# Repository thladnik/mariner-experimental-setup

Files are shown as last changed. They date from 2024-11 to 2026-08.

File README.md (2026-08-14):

## MARINER visual stimulation setup

This is the repository for MARINER - the **M**ultispectral **A**rena for **R**eal-time **I**nteractive **N**euronal and **E**thological **R**esearch. 

MARINER rendering

### Overview

[MARINER light path schematic](https://github.com/thladnik/mariner-experimental-setup/blob/main/MARINER_light_path_schematic_drawing.pdf)  (incl. dimensions for possible configuration)

[Bill of materials](https://github.com/thladnik/mariner-experimental-setup/blob/main/bill_of_materials.csv)

[Alignment guide](https://github.com/thladnik/mariner-experimental-setup/blob/main/alignment_guide/README.md)

[Explosion animations](https://github.com/thladnik/mariner-experimental-setup/blob/main/accessibility)

[Printable components](https://github.com/thladnik/mariner-experimental-setup/tree/main/printed_parts) (Mesh and design files)

### Components

#### Projector
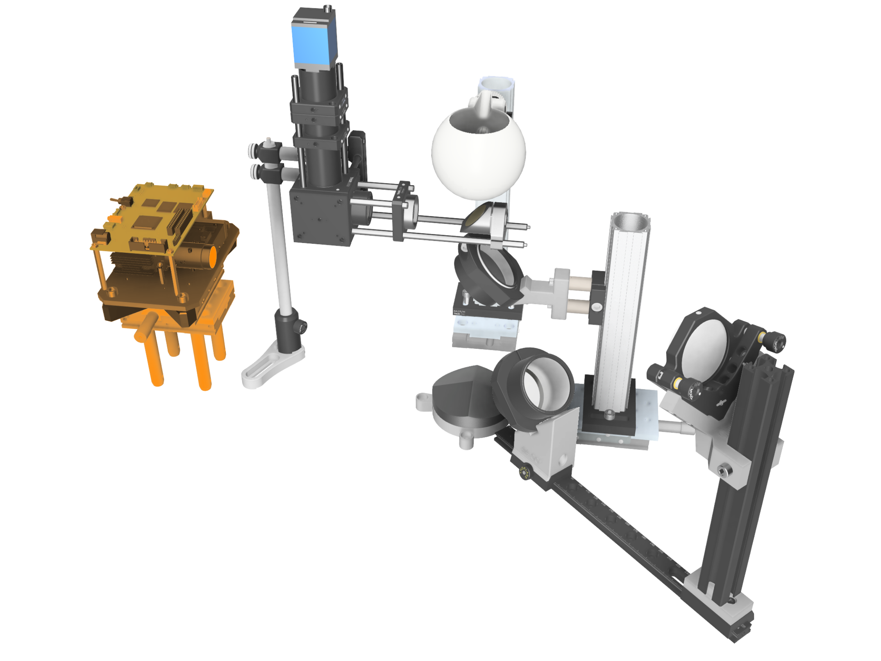
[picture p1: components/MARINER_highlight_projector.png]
MARINER projector


#### Center assembly
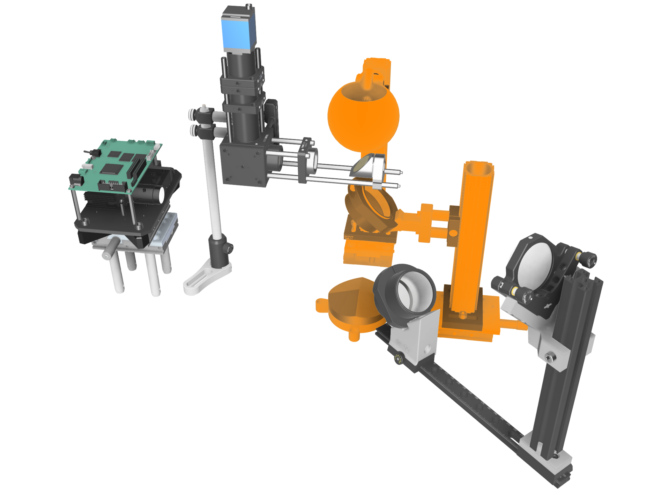
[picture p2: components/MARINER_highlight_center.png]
MARINER center assembly


#### Radial arms
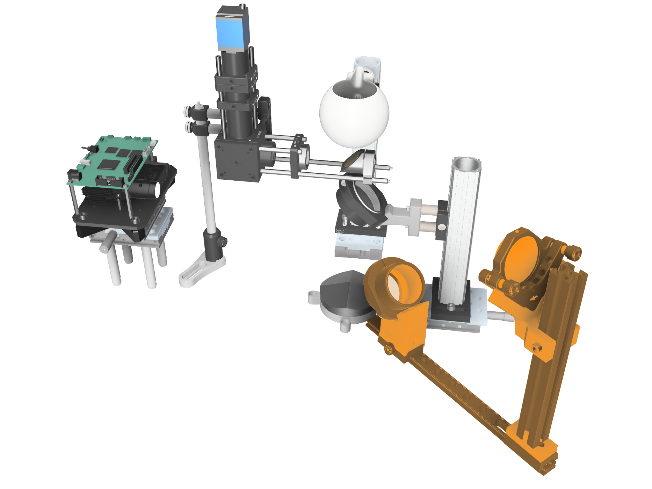
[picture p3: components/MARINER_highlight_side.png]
MARINER radial arms


#### (optional) Behavioral camera
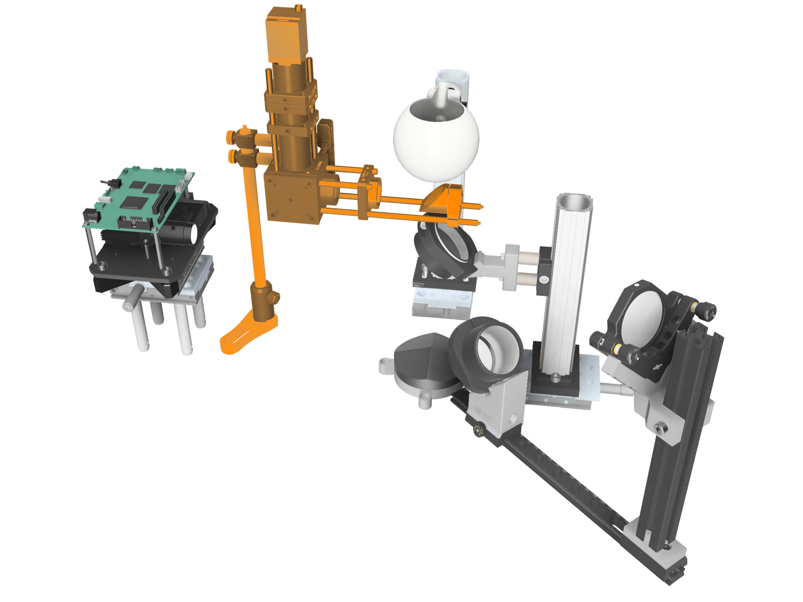
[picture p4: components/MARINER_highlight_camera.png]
MARINER camera


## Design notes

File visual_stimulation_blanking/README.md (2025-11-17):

# Circuit for blanking of the visual stimulation during 2p-imaging

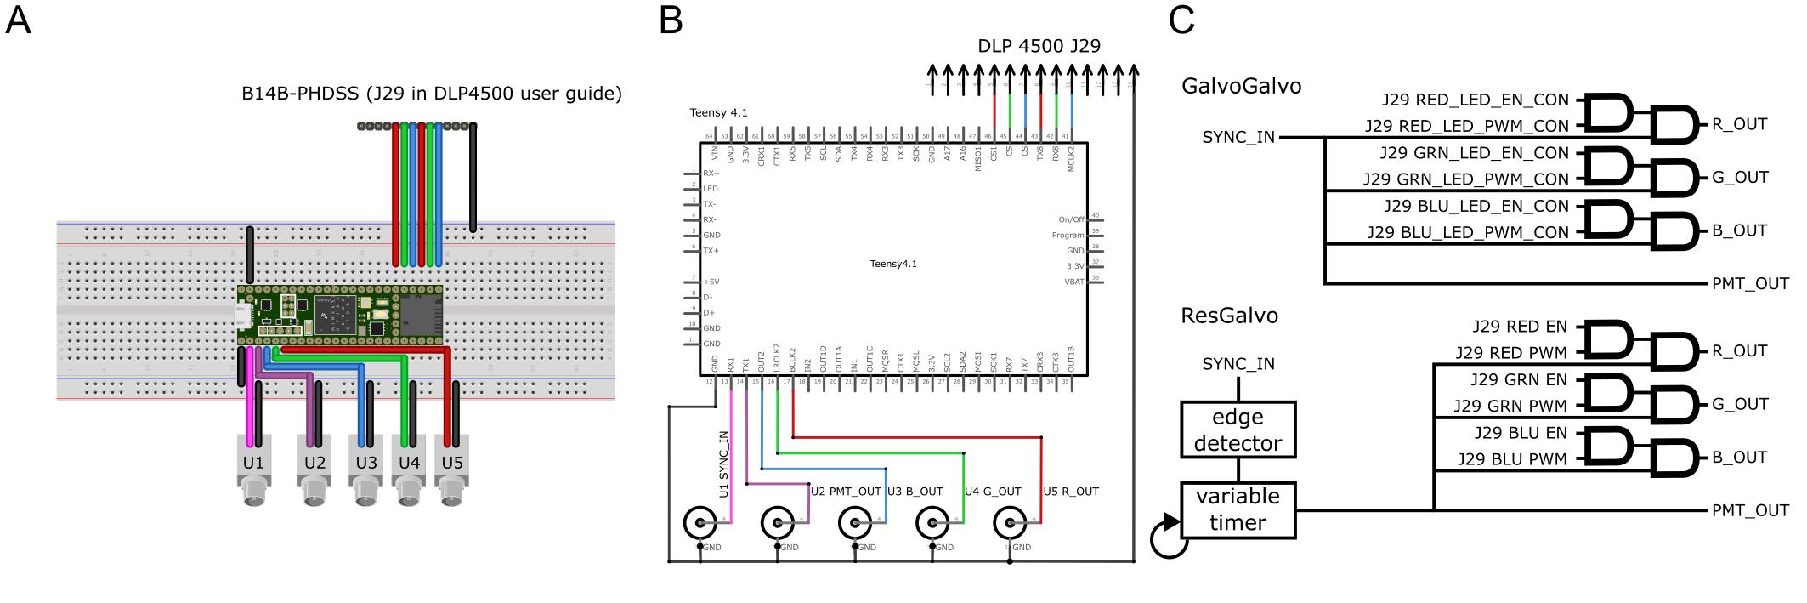
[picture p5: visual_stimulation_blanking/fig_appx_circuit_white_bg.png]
circuit-diagram-and-logic


### A and B
Image and schematic of the wiring between the Lightcrafter E4500MKII's J29 connector, the Teensy 4.1 microcontroller and the BNC input/output connectors for synchronized blanking to 2-photon imaging of the visual stimulation. 
U1 (sync_in): input for the scan synchronization signal. Either the linescan's flyback signal (for Galvo-Galvo) or the imaging frame synchronization signal (Resonant-Galvo)
U2 (pmt_out): optional digital output for gating of photomultiplier tubes (PMT).
U3-5 (<color>_out): digital output signal for controlling the LED light source (corresponding to the Lightcrafter's blue, green and red channels)

### C
Diagram of gating logic for GalvoGalvo and ResGalvo blanking. Note that both SYNC_IN and PMT_OUT may optionally be inverted, according to microscope or PMT specifications.

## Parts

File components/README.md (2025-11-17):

## Component list

Overview of the MARINER setup components references in the bill of materials ([BOM](https://github.com/thladnik/mariner-experimental-setup/blob/main/bill_of_materials.csv)).

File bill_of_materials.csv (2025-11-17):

Description | Manufacturer | Manufacturer ID | Quantity | Category | Note
Aluminum Breadboard, 600 mm x 600 mm x 12.7 mm, M6 Taps | Thorlabs | MB6060/M | 1 | Base
Industrial camera A2A1920-IMX392 | Basler | a2A1920-51gmBAS | 1 | Behavioral camera
USB 3.0 Camera Cable, Micro-B to Standard-A Plug, 8 m | Basler | Cable USB 3.0 Micro B sl/A, P, 8 m | 1 | Behavioral camera
N-BK7 Plano-Convex Lens, Ø1", f = 100 mm, AR Coating: 650–1050 nm | Thorlabs | LA1509-B | 1 | Behavioral camera
N-BK7 Plano-Convex Lens, Ø1", f = 200 mm, AR Coating: 650–1050 nm | Thorlabs | LA1708-B | 1 | Behavioral camera
30 mm Cage Cube | Thorlabs | C4W | 1 | Behavioral camera
Ø1" Optic Mount for 30 mm Cage Cube w/ Setscrew Retention | Thorlabs | B5C1 | 1 | Behavioral camera
30 mm Cage Cube Rotation Platform (Metric) | Thorlabs | B3CR/M | 1 | Behavioral camera
Blank Cover Plate, Metric | Thorlabs | B1C/M | 1 | Behavioral camera
30 mm Cage System Iris Diaphragm (Ø0.8–20 mm) | Thorlabs | CP20D | 1 | Behavioral camera
Right-Angle Kinematic Mount for Ø1" Optics, 30 mm Cage Compatible | Thorlabs | C45P | 1 | Behavioral camera
Ø1" Protected Gold Mirror | Thorlabs | PF10-03-M01 | 2 | Behavioral camera
Ø1" Adjustable Lens Tube, 0.81" Travel | Thorlabs | SM1V10 | 1 | Behavioral camera
SM1 Lens Tube, 0.50" Depth, SM1RR Retaining Ring, 5 Pack | Thorlabs | SM1L05-P5 | 1 | Behavioral camera
SM1 Lens Tube, 1.00" Depth, SM1RR Retaining Ring, 5 Pack | Thorlabs | M1L10-P5 | 1 | Behavioral camera
SM1-Threaded 30 mm Cage Plate, 0.35" Thick, 2 Retaining Rings, M4 Tap | Thorlabs | CP33/M | 3 | Behavioral camera
SM1-Threaded 30 mm Cage Plate, 0.50" Thick, 2 Retaining Rings, M4 Tap | Thorlabs | CP33T/M | 1 | Behavioral camera
30 mm Cage Plate w/ Removable Filter Holder, Ø1" Optics, M4 Tap | Thorlabs | CFH2R/M | 1 | Behavioral camera
Adapter, External C-Mount to External SM1, 3.2 mm Spacer | Thorlabs | SM1A39 | 1 | Behavioral camera
Externally SM1-Threaded End Cap | Thorlabs | SM1CP2 | 2 | Behavioral camera
Cage Assembly Rod, 8", Ø6 mm, 4 Pack | Thorlabs | ER8-P4 | 1 | Behavioral camera
Cage Assembly Rod, 4", Ø6 mm, 4 Pack | Thorlabs | ER4-P4 | 1 | Behavioral camera
Center mirror mount | 3D printed |  | 1 | Center assembly
Pyramid mirror mount | 3D printed |  | 1 | Center assembly
Bulb holder | 3D printed |  | 1 | Center assembly
Fishbowl | 3D printed |  | 1 | Center assembly
Pyramid mirror Ø80mm x 26.5mm, four-sided, 136° | LT Ultra-Precision Technology GmbH | 122680 | 1 | Center assembly | M2
50 mm Dovetail Translation Stage, M6 x 1.0 Taps | Thorlabs | DTS50/M | 2 | Center assembly | Most linear trans. stages w/ M6 taps should work
34 mm Construction Rail, L = 500 mm | Thorlabs | XT34-500 | 1 | Center assembly | Cut into 20 and 30cm piece
Magnetic Mounting Base, 50 mm x 75 mm x 10 mm | Thorlabs | BA2R/M | 2 | Center assembly
Dovetail Mounting Clamp for 34 mm Rails, Metric | Thorlabs | XT34HP/M | 2 | Center assembly
Ø12.7 mm Optical Post, SS, M4 Setscrew, M6 Tap, L = 30 mm | Thorlabs | TR30/M | 2 | Center assembly
SM2 Lens Tube Without External Threads, 1" Thread Depth | Thorlabs | SM2M10 | 1 | Center assembly
Ø2" Broadband Dielectric Mirror, 400 - 750 nm | Thorlabs | BB2-E02 | 1 | Center assembly | M1
Slip Ring for SM2 Lens Tubes, M4 Tap | Thorlabs | SM2RC/M | 1 | Center assembly
Teensy breakout box | 3D printed |  | 1 | Lighting
Socket connector, 36-pin, separable | BKL electronic | 10120802 | 4 | Lighting | Or similar socket connector
Lightcrafter LED signal connector | JST | PHDR-14VS | 1 | Lighting
Lightcrafter LED signal connector cables | JST | APAPA22K254 | 14 | Lighting
BNC cable | NEDIS | CVGL01000BK50 | 5 | Lighting | Or similar BNC cable
Microcontroller Teensy 4.1 with header | PJRC | TEENSY41H | 1 | Lighting
Dot-strip matrix PCB Laminated paper, 50x100 mm | Rademacher | H25PS050 | 1 | Lighting | Or similar dot-strip matrix PCB
BNC panel socket, central mounting, soldered vers. | Radiall | R141A 605 000 | 5 | Lighting | Or similar BNC panel socket
Chrolis 6-LED light source | Thorlabs | CHROLIS | 1 | Lighting | 625-590-565-475-420-365nm
Chrolis Breakout Box | Thorlabs | BBC1 | 1 | Lighting
Lightcrafter mounting platform | 3D printed |  | 1 | Projector
Lightcrafter lens holder | 3D printed |  | 1 | Projector
0.45" DLP® Fiber couple E4500MKII™ Development Module LLG On Axis Projection | EKB technologies | DPM-FE4500MKIIFLLGOX | 1 | Projector
7" x 4" Lab Jack, 2.26" Vertical Travel, 75 lbs Load Capacity, M6 Taps | Thorlabs | L490/M | 1 | Projector | This is mostly for convenience, 50 or 75mm 1/2" posts should also work instead (4x TR50/M or 4x TR75/M)
Ø1" Achromatic Doublet, ARC: 400 - 700 nm, f = 60 mm | Thorlabs | AC254-060-A | 1 | Projector | L1
50 mm Dovetail Translation Stage, M6 x 1.0 Taps | Thorlabs | DTS50/M | 2 | Projector | Most linear trans. stages with M6 taps should work
Set of jumper wires |  |  | ~20 | Projector | Any jumper wires compatible with choosen socket connector
Angled slip ring holder for lenses | 3D printed |  | 4 | Radial arms
Angled holder for Kinematic mirror mount | 3D printed |  | 4 | Radial arms
Construction rail mount to dovetail rail carrier | 3D printed |  | 4 | Radial arms
Slip Ring for SM2 Lens Tubes, M4 Tap | Thorlabs | SM2RC/M | 4 | Radial arms
Kinematic Mirror Mount for Ø2" Optics with Visible Laser Quality Mirror | Thorlabs | KM200-E02 | 4 | Radial arms | M3
Dovetail Optical Rail, 300 mm, Metric | Thorlabs | RLA300/M | 4 | Radial arms
Dovetail Rail Carrier, 50.8 mm x 25.4 mm, M6 Counterbore, M4 Taps | Thorlabs | RC2/M | 8 | Radial arms
Ø2" Achromatic Doublet, ARC: 400 - 700 nm, f = 75.0 mm | Thorlabs | AC508-075-A | 4 | Radial arms | L2
SM2 Lens Tube, 2" Thread Depth, One Retaining Ring Included | Thorlabs | SM2L20 | 4 | Radial arms
25 mm Square Construction Rail, 225 mm Long, M6 Taps | Thorlabs | XE25L225/M | 4 | Radial arms
Low-Profile T-Nut, M6 x 1.0 Tapped Hole, 10 Pack | Thorlabs | XE25T3/M | 2 | Radial arms

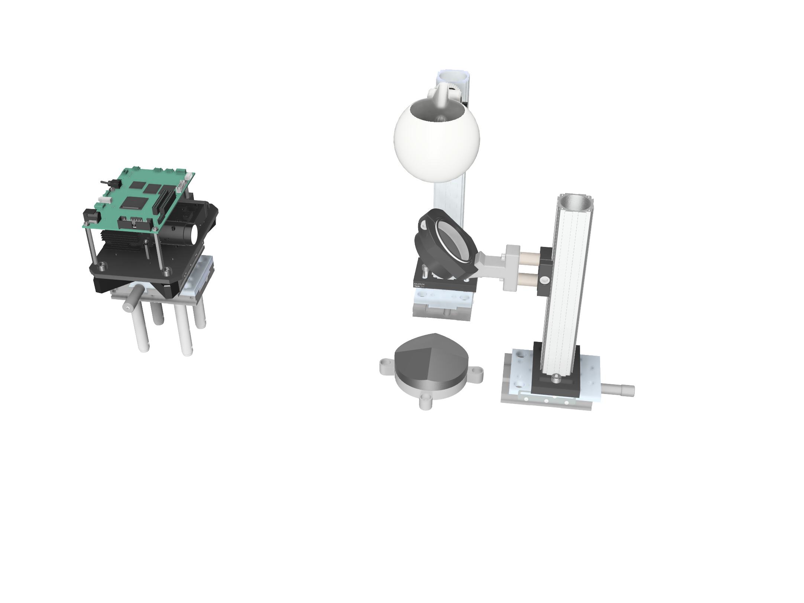
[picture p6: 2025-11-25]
components/MARINER_projector_center.png

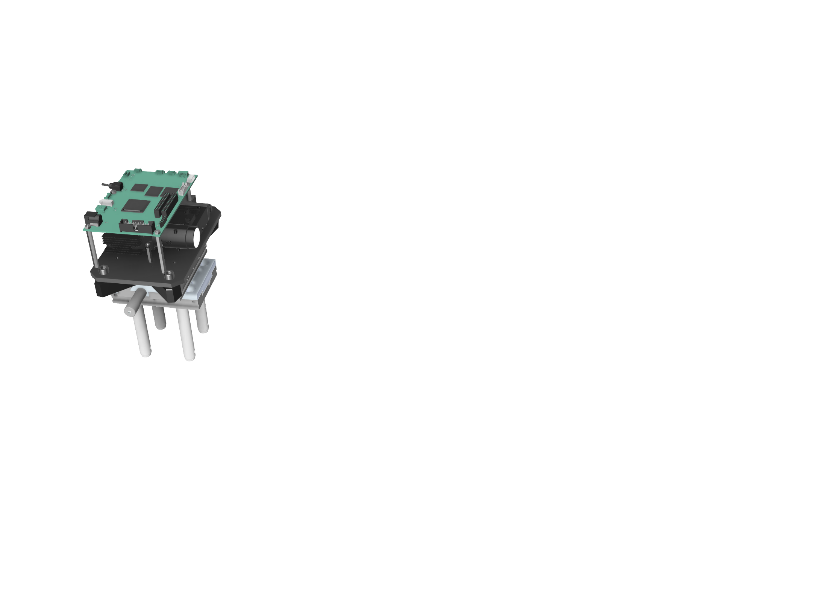
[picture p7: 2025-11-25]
components/MARINER_projector.png

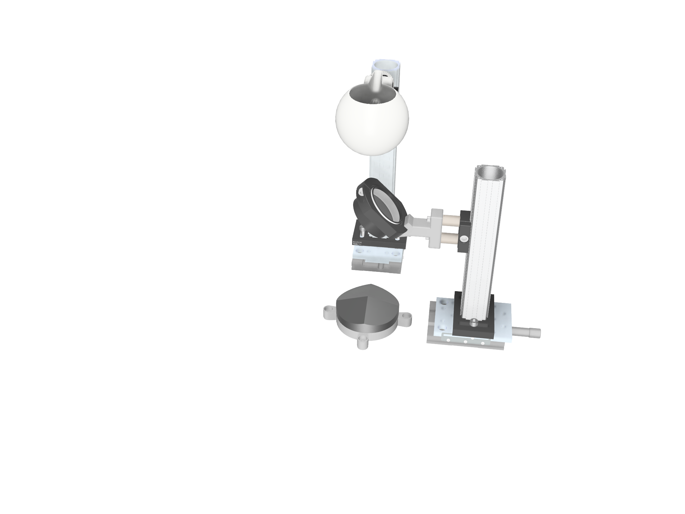
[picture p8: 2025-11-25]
components/MARINER_center.png

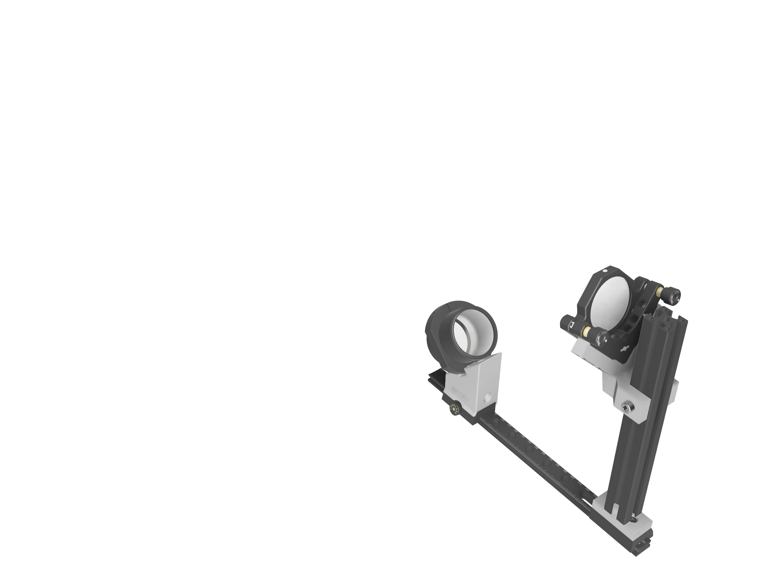
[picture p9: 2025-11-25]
components/MARINER_side.png

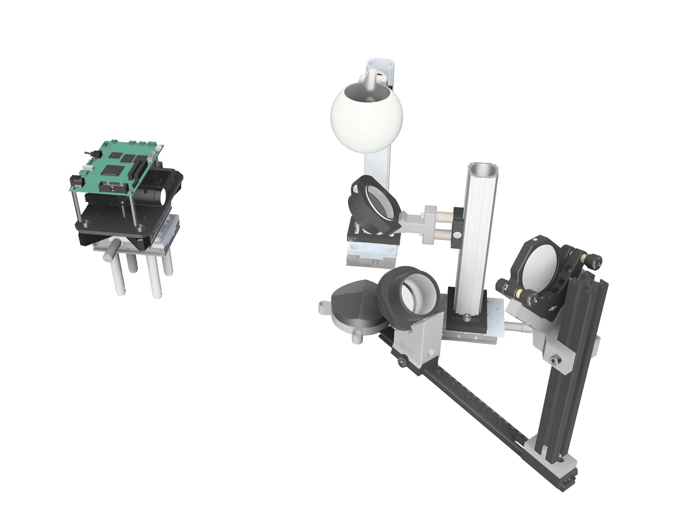
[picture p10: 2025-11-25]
components/MARINER_projector_center_side.png

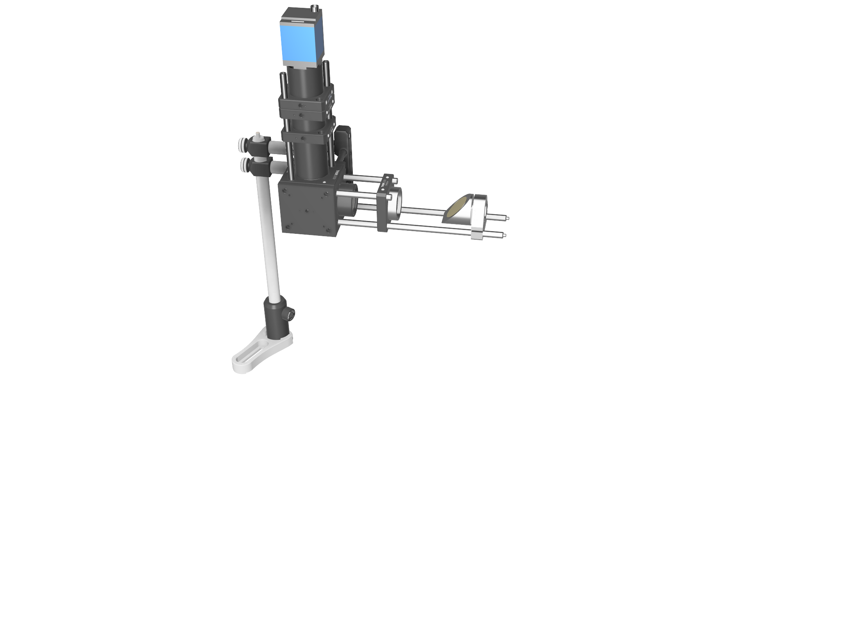
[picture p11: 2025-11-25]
components/MARINER_camera.png

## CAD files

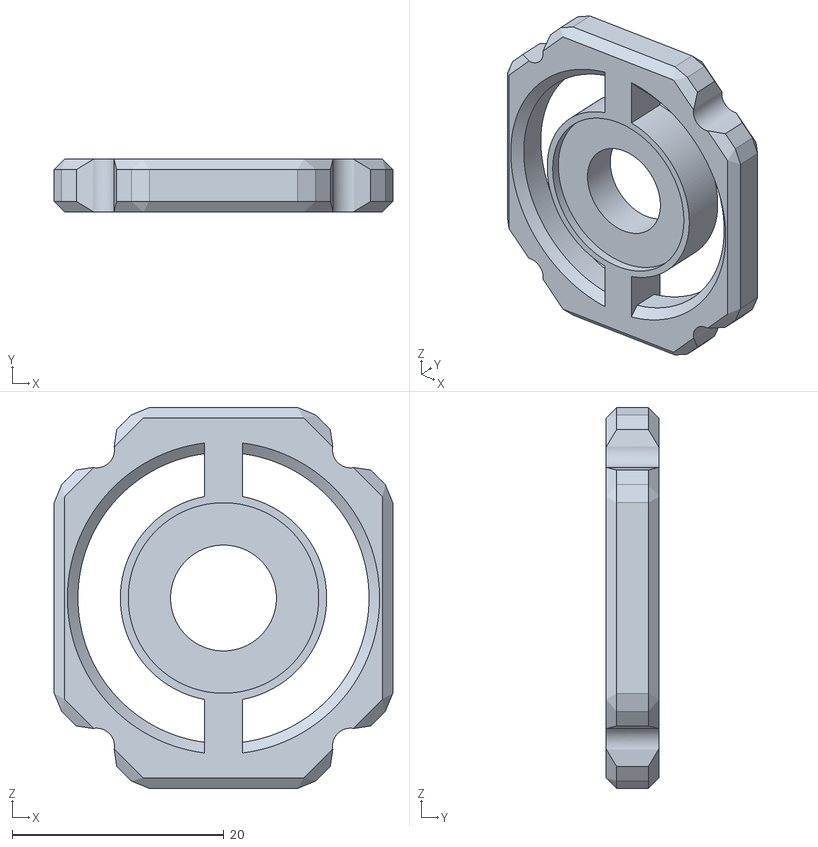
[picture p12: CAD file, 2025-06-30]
printed_parts/Fishbowl_with_rail_mount_Spacer.stl
32.0 x 5.00 x 36.0

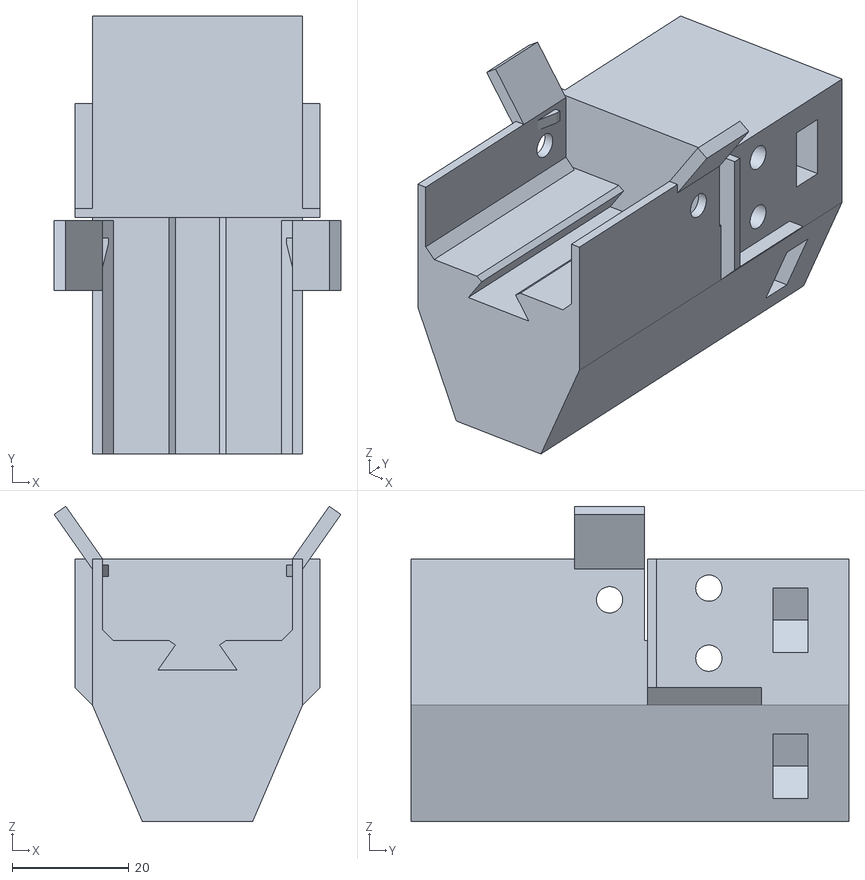
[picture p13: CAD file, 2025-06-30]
printed_parts/Fishbowl_with_rail_mount_Rail_mount.stl
49.1 x 75.0 x 54.0

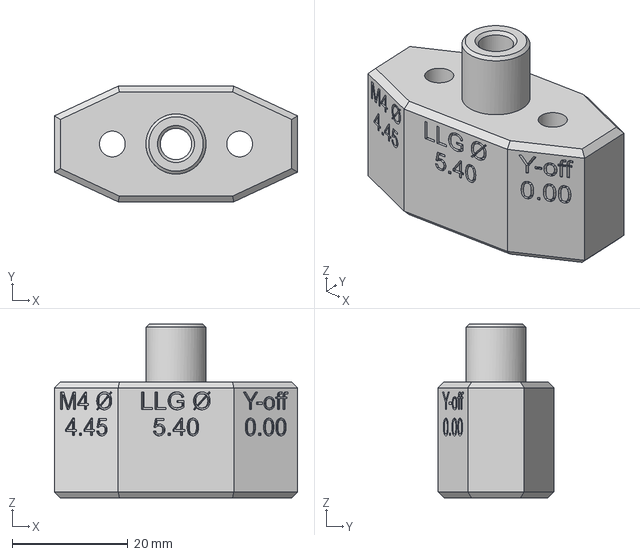
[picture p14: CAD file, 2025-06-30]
printed_parts/Lightcrafter_LLG_3mm_adapter.iges
42.0 x 20.0 x 30.0 mm

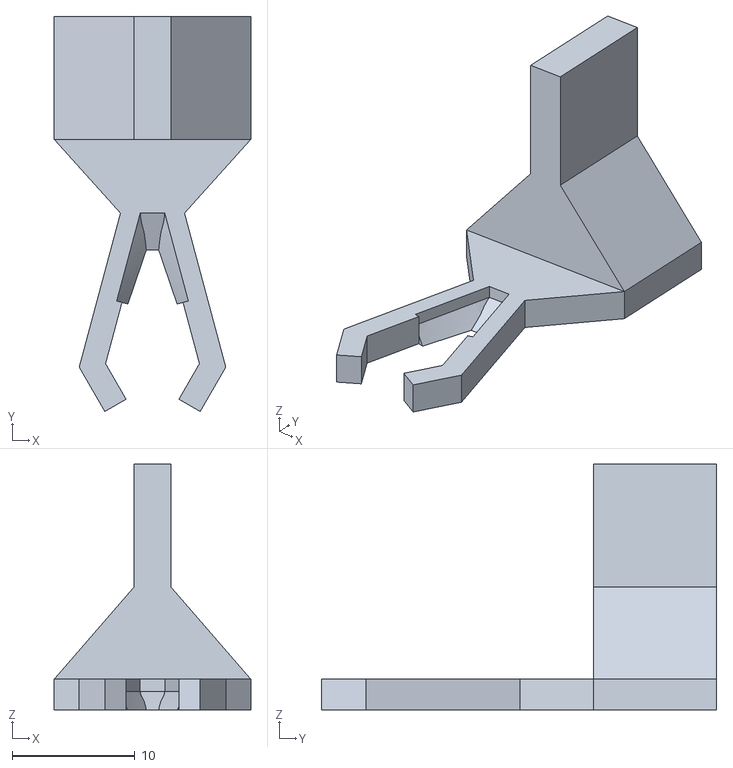
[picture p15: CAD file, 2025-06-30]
printed_parts/Fish_mounting_rod_Mold.stl
16.0 x 32.1 x 20.0

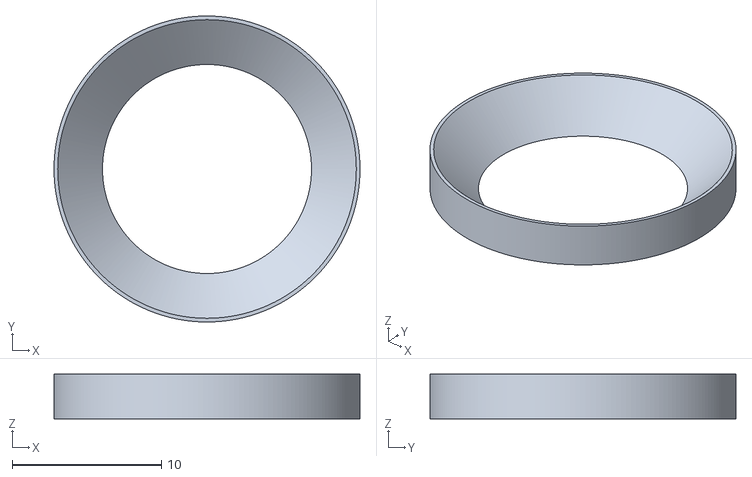
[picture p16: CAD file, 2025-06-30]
printed_parts/Lightcrafter_lens_mount_aperture.stl
20.5 x 20.5 x 3.00

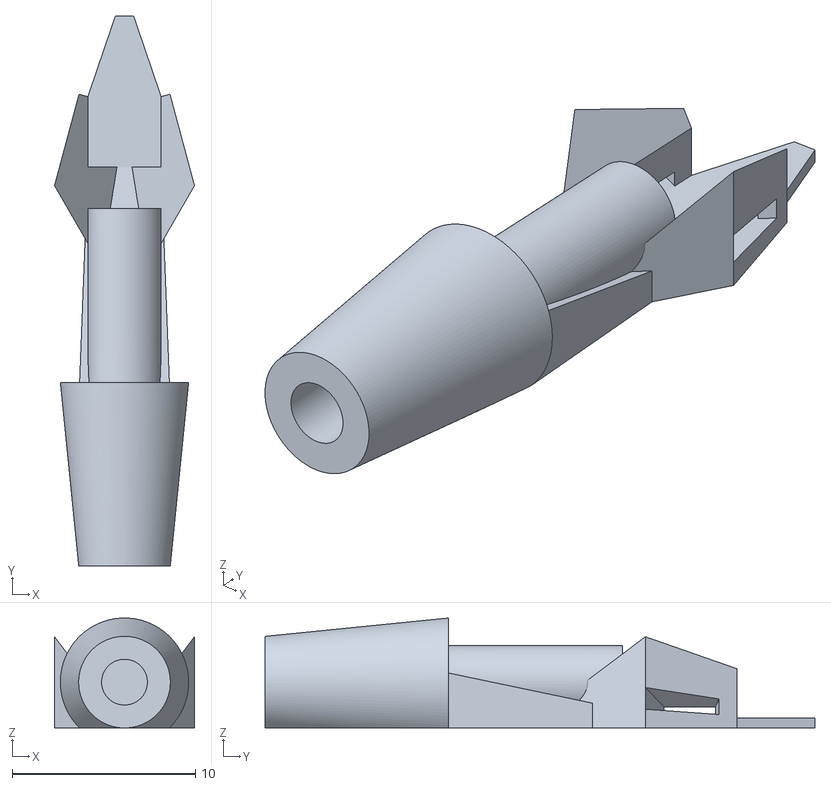
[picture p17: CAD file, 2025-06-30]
printed_parts/Fish_mounting_rod_Arrowhead.stl
7.64 x 30.0 x 6.00

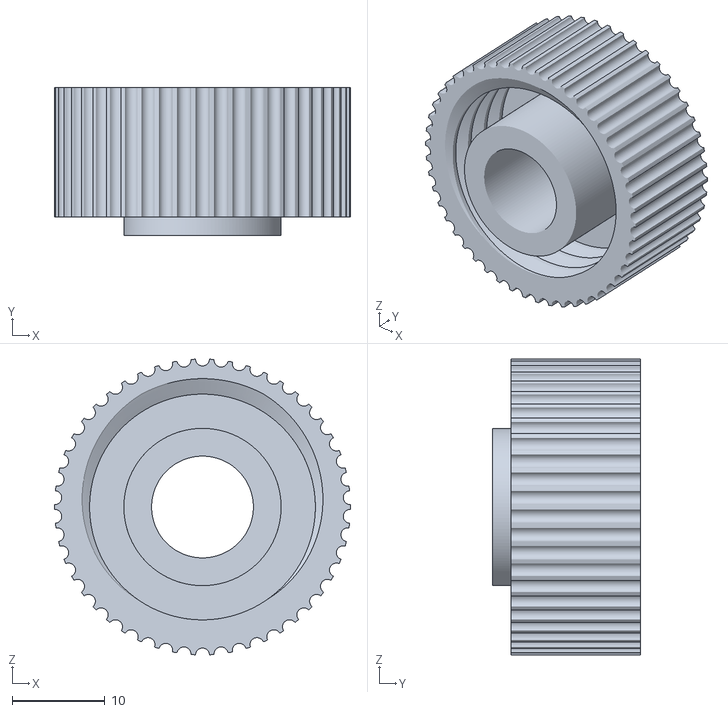
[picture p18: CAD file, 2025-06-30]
printed_parts/Fishbowl_with_rail_mount_Cap.stl
32.0 x 16.0 x 32.0

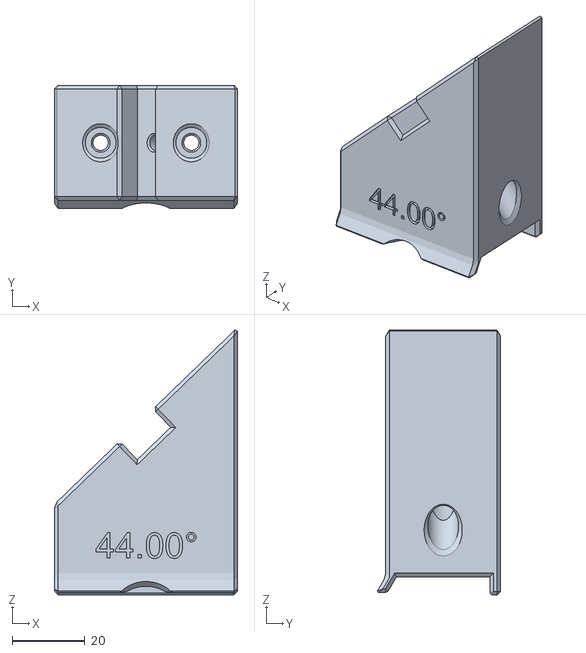
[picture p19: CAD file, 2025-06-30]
printed_parts/Lens_mount_side_44deg.stl
50.5 x 34.0 x 73.1

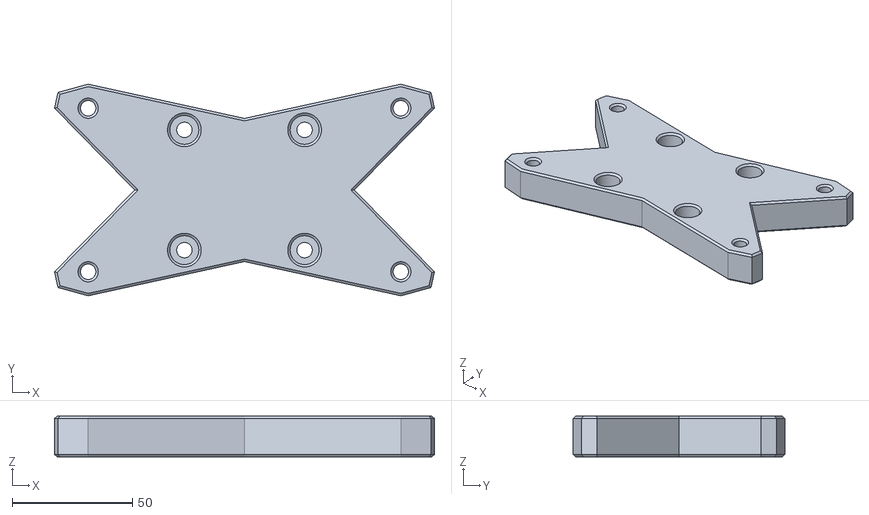
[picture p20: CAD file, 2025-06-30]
printed_parts/Lightcrafter_mounting_platform.stl
158.0 x 88.0 x 17.0

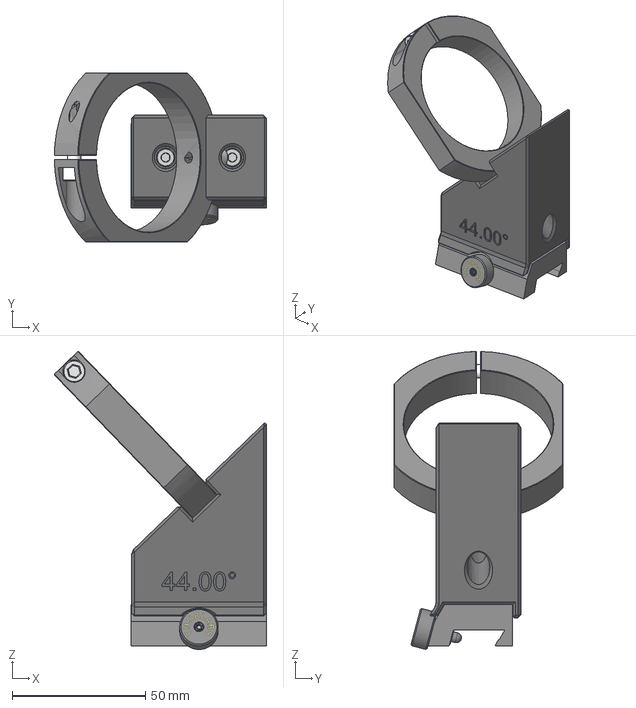
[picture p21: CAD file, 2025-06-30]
printed_parts/Lens_mount_side.iges
79.6 x 63.5 x 111.8 mm

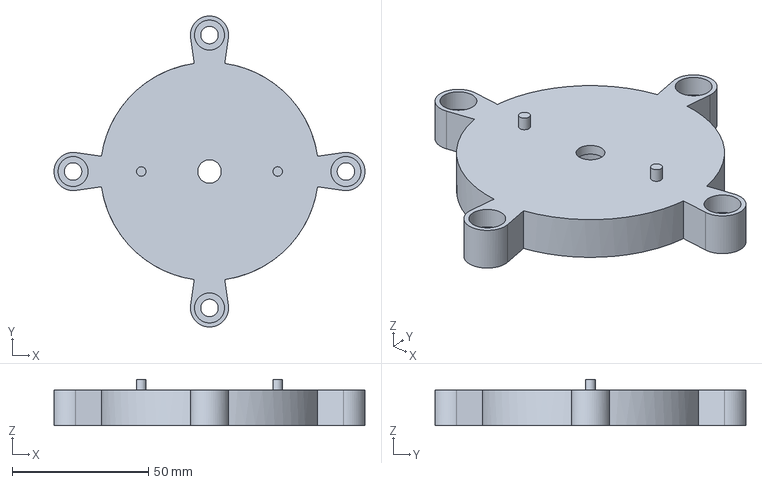
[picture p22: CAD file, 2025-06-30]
printed_parts/Pyramid_mirror_mount.iges
114.0 x 114.0 x 17.0 mm

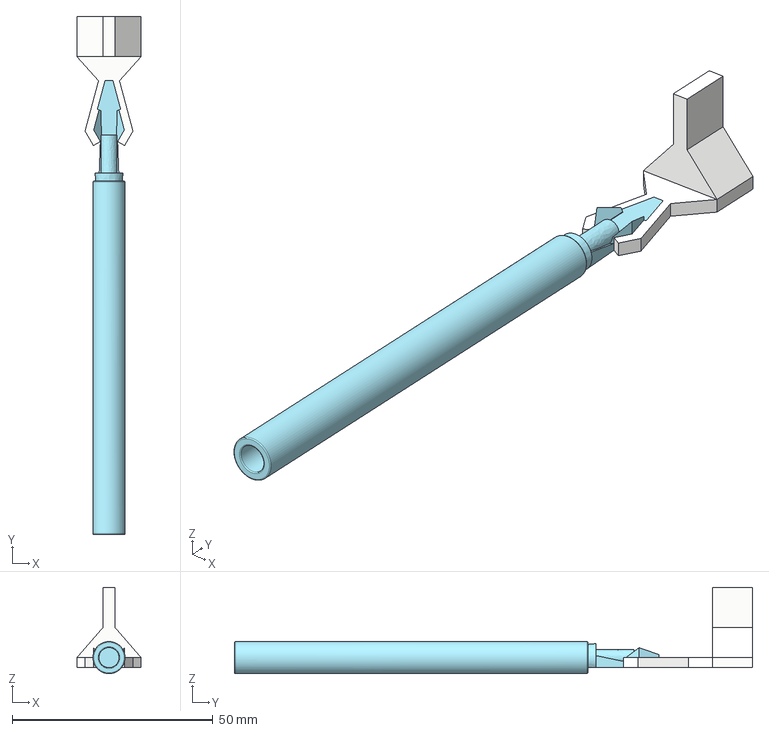
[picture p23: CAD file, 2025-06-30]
printed_parts/Fish_mounting_rod.iges
16.0 x 129.0 x 21.5 mm

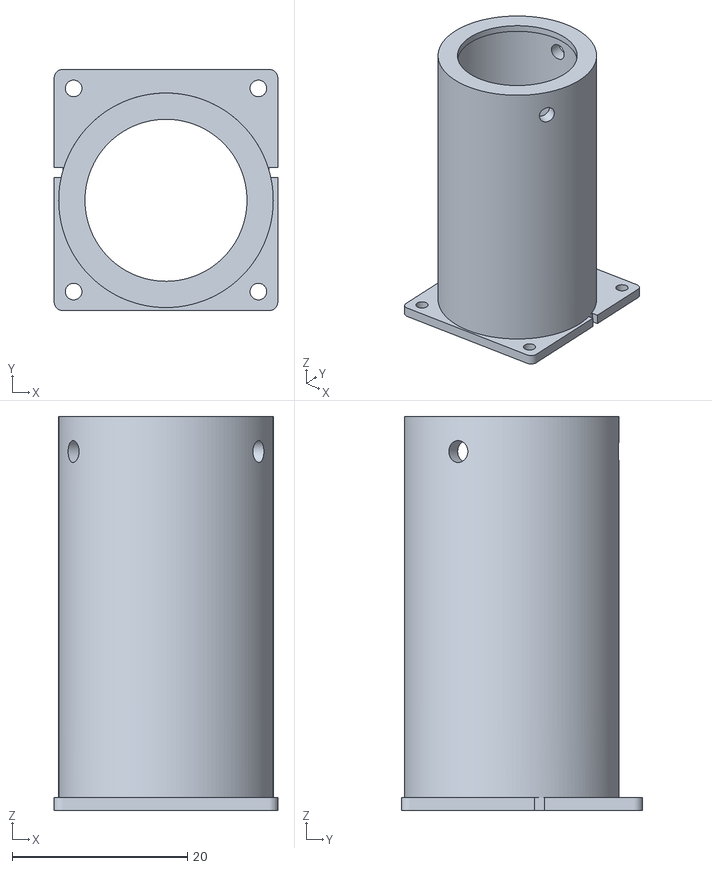
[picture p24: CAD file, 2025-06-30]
printed_parts/Lightcrafter_lens_mount_housing.stl
25.5 x 27.6 x 45.0

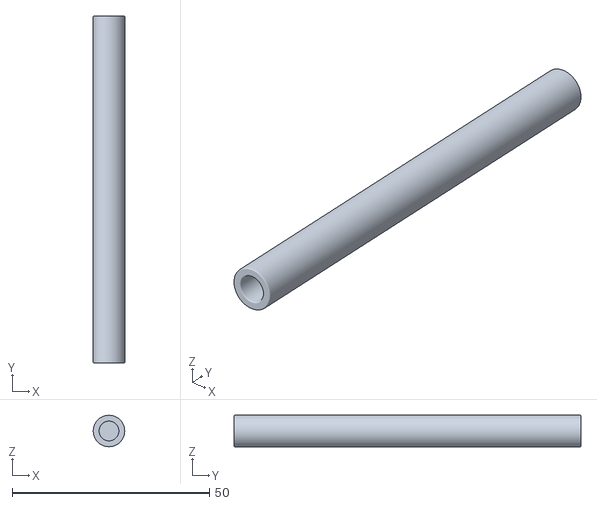
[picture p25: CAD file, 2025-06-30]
printed_parts/Fish_mounting_rod_Rod.stl
8.00 x 88.0 x 8.00

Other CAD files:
printed_parts/Fishbowl_with_rail_mount_Bulb.stl
printed_parts/Fishbowl_with_rail_mount.iges
printed_parts/Mirror_center_45deg.iges
printed_parts/Fish_mounting_rod.f3d
printed_parts/Fishbowl_with_rail_mount.f3d
printed_parts/Lens_mount_side.f3z
printed_parts/Lightcrafter_LLG_3mm_adapter.f3d
printed_parts/Lightcrafter_LLG_3mm_adapter.stl
printed_parts/Lightcrafter_lens_mount.f3d
printed_parts/Lightcrafter_mounting_platform.f3z
printed_parts/Mirror_center_45deg.f3d
printed_parts/Mirror_center_45deg.stl
printed_parts/Pyramid_mirror_mount.f3d
printed_parts/Pyramid_mirror_mount.stl

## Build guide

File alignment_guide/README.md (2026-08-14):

# Spherical Projection Setup — Light Path & Alignment Tutorial

This tutorial explains how the projection light path of the spherical MARINER stimulation setup works and walks you through aligning it from scratch. It is written for both new and experienced users: Section 1–2 give you the background you need to understand *why* each adjustment exists; Sections 3–5 are the hands-on procedure you can follow step by step at the rig.

---

## 1. System overview

The setup projects visual stimuli onto a **glass sphere** using a **single video projector** whose image is split into **four separate projections**, one per side of the sphere.

The visual transform required for the four-sided clover projection is available in the accompanying stimulation software [vxPy](https://github.com/thladnik/vxpy). 
The MARINER setup calibration may be started using vxPy's calibration function (`vxpy -c path/to/config.yaml calibrate`). For further information please refer to the software documentation.

The main hardware components are:

| Component | Role |
|---|---|
| **LightCrafter video projector** (on a sideways translation stage + dovetail rail) | Image source (DMD-based projector) |
| **Custom projection lens** — 1/2″ 40 mm lens (1″ 40 mm for the FC variant) | Replaces/extends the stock projector optics |
| **45° mirror** | Folds the horizontal projector beam downward |
| **4-sided pyramidal mirror** | Splits the image into four quadrants, one per projection arm |
| **4× lenses at 46° to horizontal** — 2″ f = 75 mm achromats | Refocus each image quadrant on its way out to the side |
| **4× kinematic mirrors at 12 to 14°** | Redirect each refocused quadrant up and onto the glass sphere |
| **Fishbowl** | The projection target |

**Why a 4-sided pyramidal mirror?** Covering the sphere from four sides gives steeper angles of incidence on the sphere surface, more even illumination, and less out-of-focus light than fewer, shallower projections would.

---

## 2. The light path, step by step

Light path schematic: LightCrafter → 45° mirror → pyramidal mirror → 46° lens → 12° kinematic mirror → glass sphere

*Figure 1 — The full light path (one of the four arms shown, side view). The numbered badges match the steps below.*

Follow one image quadrant from projector to sphere:

1. The **LightCrafter** projects the full stimulus image horizontally through its **custom lens**.
2. The **45° mirror** folds the beam straight down.
3. The beam lands centered on the apex of the **4-sided pyramidal mirror**, which splits the image into its four quadrants and reflects each quadrant outward toward one of the four sides.
4. Each quadrant passes through a **46° lens** (2″ f = 75 mm achromat), which refocuses that part of the image.
5. A **12° kinematic mirror** on each side reflects the refocused quadrant back toward the center and up onto the **glass sphere**.

When everything is aligned, the four quadrants form a four-lobed pattern that is perfectly centered on the pyramidal mirror, and the four projections meet seamlessly on the sphere.

---

## 3. Before you start

- All software adjustments described below are made in the **startup configuration window** of the display software, mainly on the **DISPLAY tab**. You will use:
  - **Display calibration → Planar Checkerboard** (with its vertical/horizontal spatial-frequency settings) as the main test pattern for centering the image.
  - The **spherical mesh** pattern (or the checkerboard) for aligning the side arms.
  - The **X-position / Y-position** offset settings (Global section) and the **radial offset** and **scale** settings (Spherical section).
- The alignment order matters. Work through the sections in sequence:
  1. Center the image on the pyramidal mirror (Section 4).
  2. Fine-tune X/Y centering with the checkerboard procedure (Section 4.3).
  3. Align each of the four side arms (Section 5).

---

## 4. Center part: getting the image onto the pyramidal mirror

The goal of this stage is to have the projected image land **centered on the apex of the pyramidal mirror**, with the light path passing through the **center of the projection lens**. If the beam is off-axis through the lens or off-center on the pyramid, the four quadrants will be unevenly sized and distorted downstream (see Section 4.3 for how to detect and fix this).

Center alignment: X via translation stage (top view), Y via 45° mirror rail and slip ring (side view), goal pattern

*Figure 2 — The two centering adjustments and the target result: four symmetric lobes centered on the pyramid apex.*

### 4.1 X translation (left–right)

The X position of the image on the pyramidal mirror is adjusted **physically**, by moving the **LightCrafter sideways on its translation stage**. Sliding the projector left/right shifts the image left/right on the pyramid.

### 4.2 Y translation (front–back)

There is no single knob for Y. Instead, combine two movements of the **45° mirror**:

- **Up–down** movement of the mirror mount along the vertical optical rail, and
- **Forward–backward** movement of the mirror within its slip ring.

Together these shift the image along the Y axis on the pyramidal mirror. Iterate both until the four-lobed test pattern sits centered on the pyramid apex (compare with the "end result" reference: four symmetric lobes, one per mirror facet).

### 4.3 Fine centering with the Planar Checkerboard (parallax method)

Even when the image *looks* centered, it may still pass **off-axis** through the projection lens — note that with the custom lens, the image on the DMD chip itself may be off-axis. The following software-assisted procedure detects this: if the projection axis is off-center, the image will drift sideways when you change the virtual target distance.

Display the **Planar Checkerboard** pattern, then move the **target slider from front to back** and watch how the image moves.

Parallax check: off-axis light paths make the image drift when the target distance changes; a centered path does not

*Figure 3 — The parallax check. Only a light path through the lens center keeps the image stationary while the target slider is swept.*

**X alignment:**

- Image drifts **left** as the target moves back:
  1. **Decrease** the **X-position** offset setting.
  2. Move the target slider back to the front.
  3. Move the **translation stage left** to re-center the image.
- Image drifts **right**:
  1. **Increase** the **X-position** offset setting.
  2. Move the target to the front.
  3. Move the **translation stage right** to re-center.

**Y alignment (same logic, vertical axis):**

- Image drifts **up** as the target moves back:
  1. **Increase** the **Y-position** offset setting.
  2. Move the target to the front.
  3. Re-center the image **upward** (using the 45° mirror rail/slip-ring adjustments from Section 4.2).
- Image drifts **down**:
  1. **Decrease** the **Y-position** offset setting.
  2. Move the target to the front.
  3. Re-center the image **downward**.

Repeat each loop until sweeping the target slider from front to back no longer shifts the image. At that point the light path is centered through the lens and on the pyramid.

---

## 5. Side arms (repeat 4×)

Each of the four projection arms is aligned independently, but with the same procedure. Each arm consists of a **46° lens** (2″ f = 75 mm achromat) and a **12° kinematic mirror**; the lens refocuses the quadrant, and the mirror sends it up onto the sphere.

Side arm degrees of freedom: lens height and focus, mirror height and distance, kinematic elevation and azimuth

*Figure 4 — All adjustment axes of one side arm, and the order in which to work through them (Sections 5.1–5.4).*

### 5.1 Find the optical center of the arm's lens

1. In the software, set a **fixed radial offset**.
2. Set the **scale multiplier small (< 0.2)** — this shrinks the quadrant to a small patch so you can see where it passes through the lens.
3. Display the **spherical mesh** or **checkerboard** pattern.
4. Adjust until the light path passes through the **center of the lens**.

> **Tip:** Low-f lenses produce pincushion distortion toward their edges — another reason the beam must go through the lens center rather than near its rim.

### 5.2 Lens alignment

The lens has two degrees of freedom:

- **Lens height** — translate the lens mount along its rail.
- **Lens focus** — translate the lens within its slip ring, along the optical axis.

### 5.3 Mirror holder alignment

The kinematic mirror's holder can be adjusted in **height** and in **distance** (along its rail). Use these to:

- move the image **into focus** on the sphere,
- **scale** the image, and
- change the **vertical image offset** on the sphere.

### 5.4 Kinematic mount fine-tuning

Finally, use the kinematic mount's adjustment screws to set the projection's:

- **Elevation** on the sphere, and
- **Azimuth** on the sphere.

This places the quadrant precisely on its quarter of the sphere. Repeat Sections 5.1–5.4 for the remaining three arms.

> **Note:** the kinematic mirror is mounted at a 45° around the optical axis, so that the adjustment screws are positioned symmetrically. This means for pure azimuth or elevation adjustments both screws need to be adjusted simultaneously.

---

## 6. Verifying the alignment

You are done when:

- The four-lobed test pattern is symmetric and centered on the pyramidal mirror (Section 4).
- Sweeping the checkerboard target slider front↔back produces no image drift in X or Y (Section 4.3).
- Each quadrant passes through the center of its side lens, is in focus on the sphere, and the four projections meet at the correct elevation and azimuth so the sphere is covered evenly from all four sides (Section 5).

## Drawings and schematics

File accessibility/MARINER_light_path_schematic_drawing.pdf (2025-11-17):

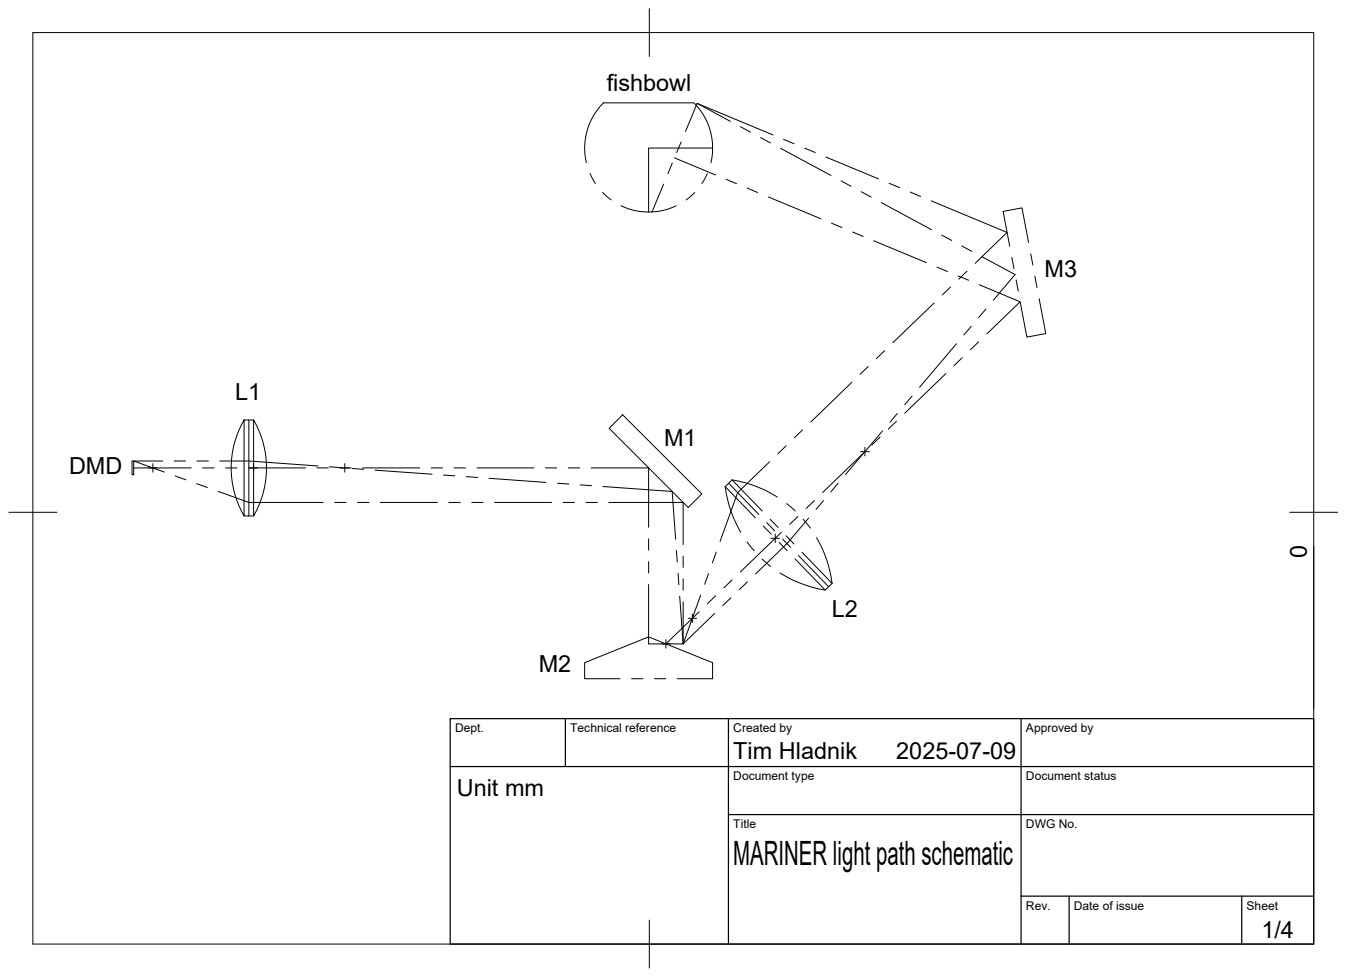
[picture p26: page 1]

Dept. | Technical reference | Created by Tim Hladnik 2025-07-09 | Approved by

Unit mm | | Document type | Document status

Title MARINER light path schematic | DWG No.

Rev. | Date of issue | Sheet

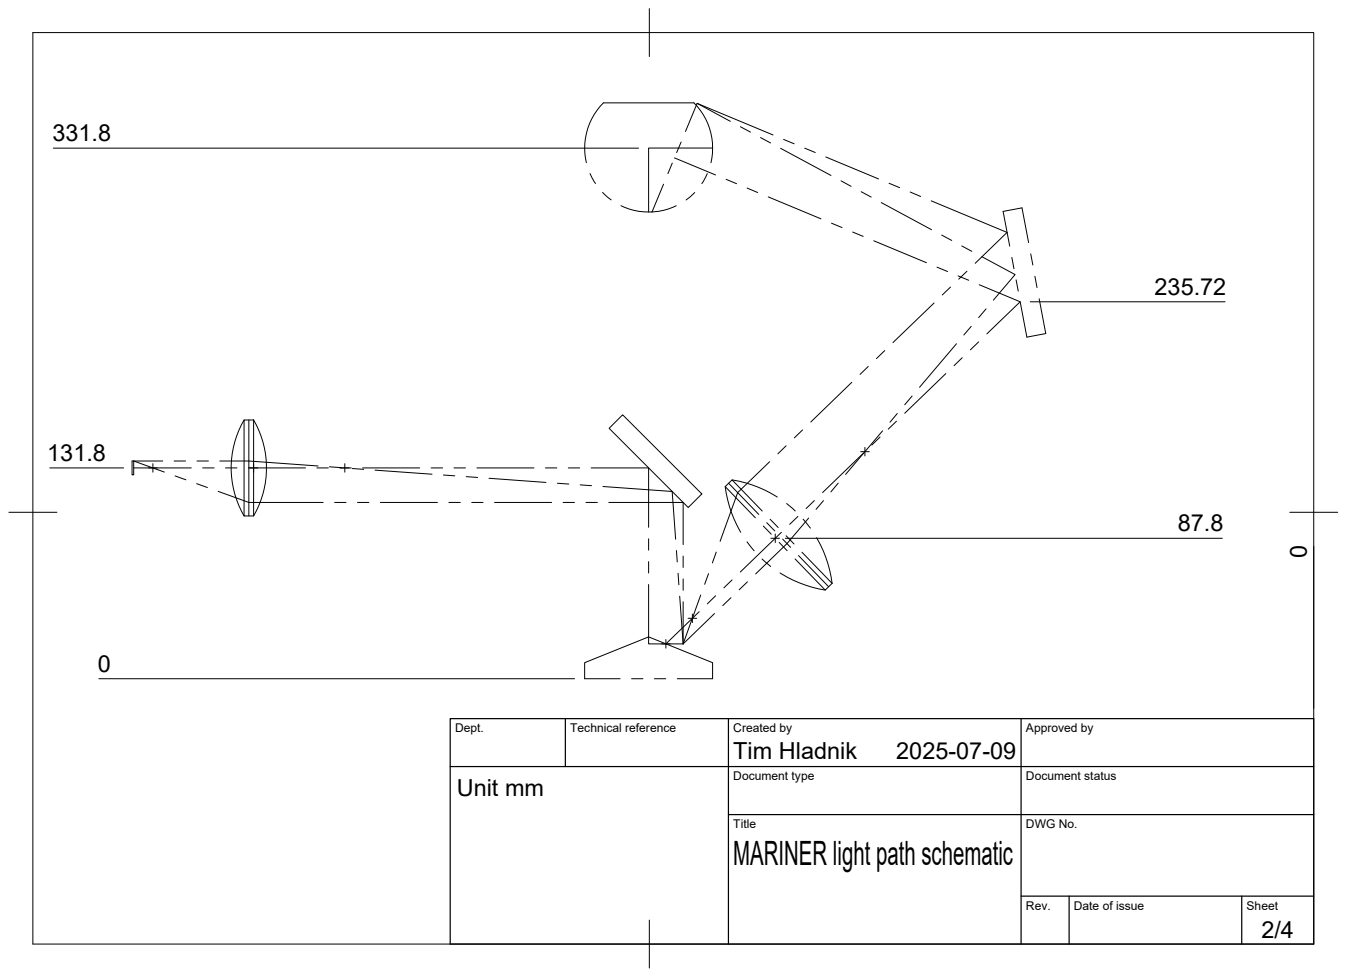
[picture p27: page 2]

Dept. | Technical reference | Created by Tim Hladnik 2025-07-09 | Approved by

Unit mm | | Document type | Document status

Title MARINER light path schematic | DWG No.

Rev. | Date of issue | Sheet

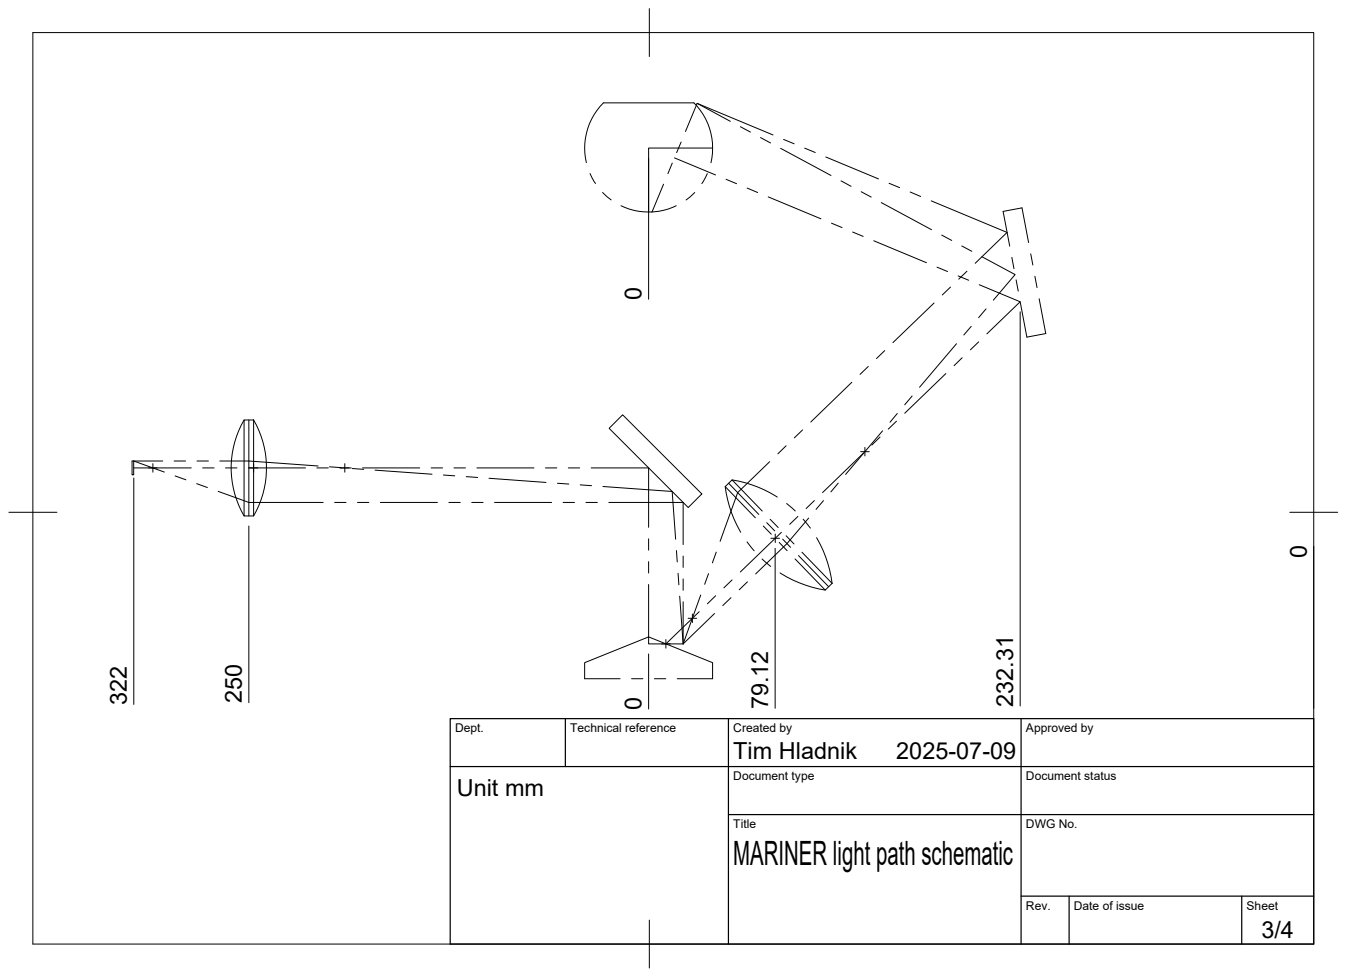
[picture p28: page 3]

Dept. | Technical reference | Created by Tim Hladnik 2025-07-09 | Approved by

Unit mm | | Document type | Document status

Title MARINER light path schematic | DWG No.

Rev. | Date of issue | Sheet

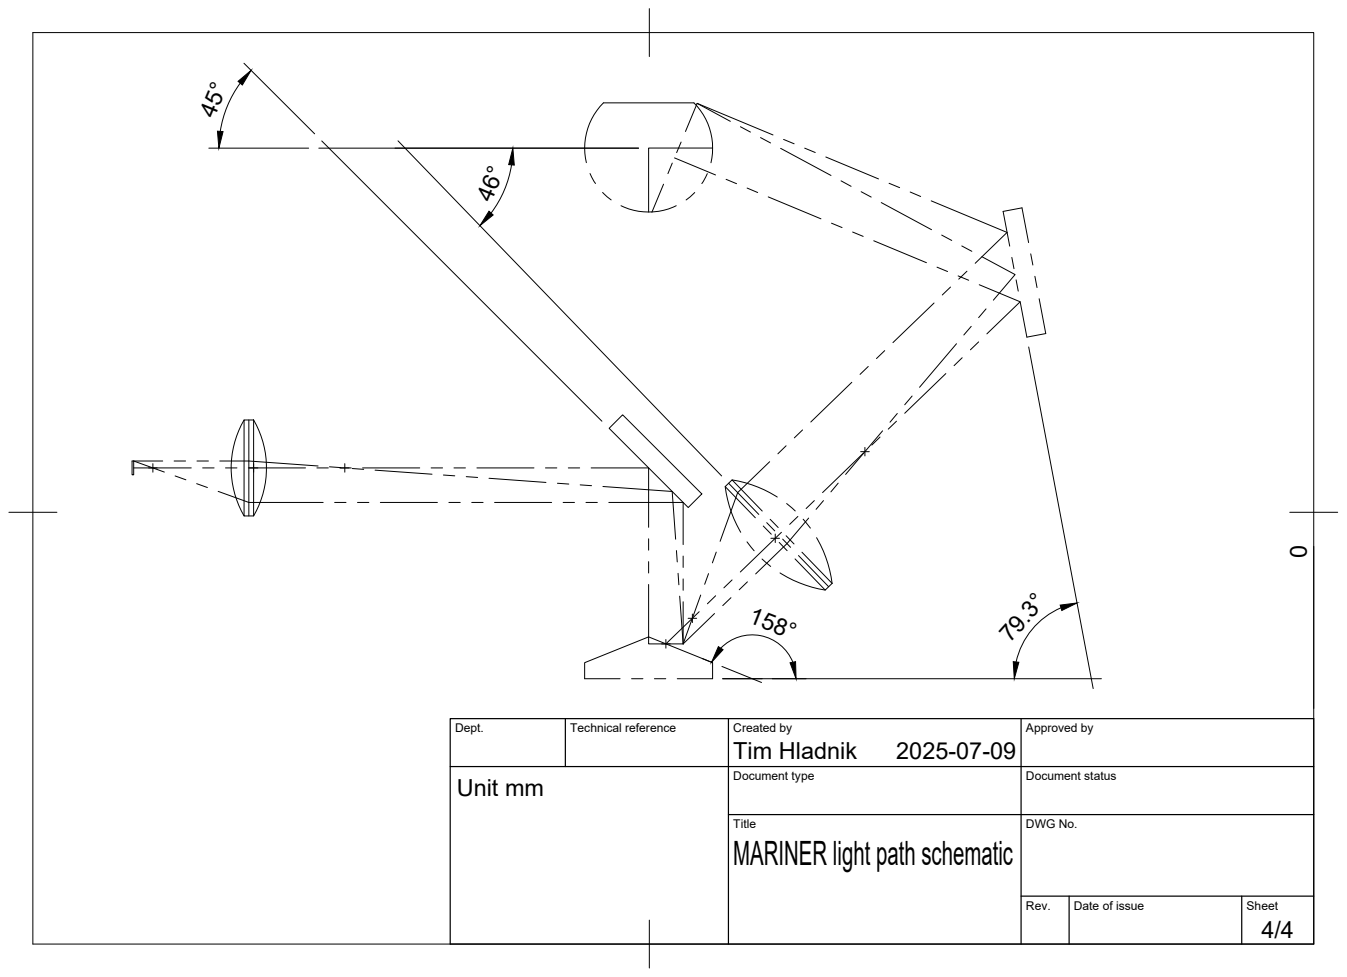
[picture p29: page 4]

Dept. | Technical reference | Created by Tim Hladnik 2025-07-09 | Approved by

Unit mm | | Document type | Document status

Title MARINER light path schematic | DWG No.

Rev. | Date of issue | Sheet

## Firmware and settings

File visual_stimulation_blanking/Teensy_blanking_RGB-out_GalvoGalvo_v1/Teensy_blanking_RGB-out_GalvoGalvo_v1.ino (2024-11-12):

// INPUTS
const int redin1 = 38;
const int redin2 = 35;
const int greenin1 = 37;
const int greenin2 = 34;
const int bluein1 = 36;
const int bluein2 = 33;

const int blankin = 0;

// OUTPUTS
const int redout = 4;
const int greenout = 3;
const int blueout = 2;
const int pmtgateout = 1;

// STATES
int redstate = 0;
int greenstate = 0;
int bluestate = 0;

int pmtgatestate_last = 0;
int pmtgatestate_cur = 0;

void setup() {

  pinMode(redin1, INPUT);
  pinMode(redin2, INPUT);
  pinMode(greenin1, INPUT);
  pinMode(greenin2, INPUT);
  pinMode(bluein1, INPUT);
  pinMode(bluein2, INPUT);
  pinMode(blankin, INPUT);
  
  pinMode(redout, OUTPUT);
  pinMode(greenout, OUTPUT);
  pinMode(blueout, OUTPUT);
  pinMode(pmtgateout, OUTPUT);

}

void loop() {
  // Read current blanking state
  // If mirror flyback period signal is used:
  pmtgatestate_cur = not(digitalReadFast(blankin));
  // If laser blanking signal is used: PMT GATE should be LOW while laser is on (HIGH)
  //pmtgatestate_cur = not(digitalReadFast(blankin));

  redstate = digitalReadFast(redin1) && digitalReadFast(redin2);
  greenstate = digitalReadFast(greenin1) && digitalReadFast(greenin2);
  bluestate = digitalReadFast(bluein1) && digitalReadFast(bluein2);

  // If PMT GATE STATE is ON && it was NOT ON during last iteration
  // SWITCH PMT OFF (Set PMT GATE to HIGH)
  if(pmtgatestate_cur && not(pmtgatestate_last)) {
    // Close PMT gate
    digitalWriteFast(pmtgateout, HIGH);
    
    // (optional?) Delay LED ON by rise time of PMT gate
    // HAMAMATSU H11706P-40:
    //  0% -> 90%  230ns
    //  0% -> 100% 400ns
    //delayNanoseconds(400);
  }

  // Write LED pins
  // LEDs should only be HIGH if PMT GATE is HIGH
  digitalWriteFast(redout, pmtgatestate_cur && redstate);
  digitalWriteFast(greenout, pmtgatestate_cur && greenstate);
  digitalWriteFast(blueout, pmtgatestate_cur && bluestate);

  // Switch PMT ON
  if(not(pmtgatestate_cur) && pmtgatestate_last) {
    // Open PMT gate
    digitalWriteFast(pmtgateout, LOW);
  }

  pmtgatestate_last = pmtgatestate_cur;
  
}

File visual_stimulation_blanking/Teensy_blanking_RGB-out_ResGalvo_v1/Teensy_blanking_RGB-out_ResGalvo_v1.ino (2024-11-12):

// INPUTS
const int redin1 = 38;
const int redin2 = 35;
const int greenin1 = 37;
const int greenin2 = 34;
const int bluein1 = 36;
const int bluein2 = 33;

const int syncin = 0;

// OUTPUTS
const int redout = 4;
const int greenout = 3;
const int blueout = 2;
const int pmtgateout = 1;

// STATES
int redstate = 0;
int greenstate = 0;
int bluestate = 0;

int sync_sig_last = 0;
int sync_sig_cur = 0;

int led_on_state = 0;
long led_on_start_time_mu = 0;
long led_on_end_time_mu = 0;
int led_on_duration_mu = 1000;

long cur_time_mu = 0;

void setup() {

  pinMode(redin1, INPUT);
  pinMode(redin2, INPUT);
  pinMode(greenin1, INPUT);
  pinMode(greenin2, INPUT);
  pinMode(bluein1, INPUT);
  pinMode(bluein2, INPUT);
  pinMode(syncin, INPUT);
  
  pinMode(redout, OUTPUT);
  pinMode(greenout, OUTPUT);
  pinMode(blueout, OUTPUT);
  pinMode(pmtgateout, OUTPUT);

}

void loop() {
  // Read ScanImage frame sync signal
  sync_sig_cur = digitalReadFast(syncin);

  // Read Lightcrafter LED PWM and EN states
  redstate = digitalReadFast(redin1) && digitalReadFast(redin2);
  greenstate = digitalReadFast(greenin1) && digitalReadFast(greenin2);
  bluestate = digitalReadFast(bluein1) && digitalReadFast(bluein2);

  cur_time_mu = micros();

  // If frame sync signal changes from HIGH to LOW, turn LEDs on
  if(not(sync_sig_cur) && sync_sig_last) {
    led_on_state = HIGH;
    led_on_start_time_mu = cur_time_mu;
    led_on_end_time_mu = led_on_start_time_mu + led_on_duration_mu;
  }

  // Turn LEDs off if current time is not between start and end times
  if(not((led_on_start_time_mu <= cur_time_mu) && (cur_time_mu <= led_on_end_time_mu))) {
    led_on_state = LOW;
  }

  // Set LED pin outputs
  digitalWriteFast(redout, led_on_state && redstate);
  digitalWriteFast(greenout, led_on_state && greenstate);
  digitalWriteFast(blueout, led_on_state && bluestate);

  // (optional) Set PMT gate output (original led_on_state or inverted version, depending on PMT type)
  // digitalWriteFast(pmtgateout, not(led_on_state));
  digitalWriteFast(pmtgateout, led_on_state);

  sync_sig_last = sync_sig_cur;
  
}
